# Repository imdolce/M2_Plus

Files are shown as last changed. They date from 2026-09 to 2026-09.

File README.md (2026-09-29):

# M2 Plus - 3-Phase BLDC Controller & 3A Fast-Charge Control Board







**M2 Plus** is an open-source, high-performance controller engineered as a replacement for the stock controller board came after purchase.

Built around the **WCH CH32V003F4U6** (32-bit RISC-V @ 48 MHz), the system integrates a **TI TPS61088** 10A synchronous boost converter, an **Allegro AMT49406** sensorless 3-phase BLDC controller with 6 external **AO3400** power MOSFETs, an **Injoinic IP2312** 3A fast charger with an **XB5606AJ** 1S protection circuit, and an auxiliary **WLED Breakout** daughterboard with 4x WS2812B addressable RGB LEDs and tactile button.

The project features auto-programming EEPROM configuration, 10-step throttle mapping, soft-start, smooth torque ramps, and context-aware RGB lighting animations.

> [!IMPORTANT]
> The hardware design consists of **two discrete PCBs**:
> 1. **M2 Plus Mainboard**: Handles charging, power delivery, motor control, MCU.
> 2. **WLED Breakout Board**: Houses the 4x WS2812B-2020 RGB status LEDs and the multi-function tactile user button.
> Interactive HTML Bill of Materials (iBOM) are provided for both boards in [`pcb/bom/`](pcb/bom/), and 3D CAD models in [`pcb/cad/`](pcb/cad/).

---

## PCB Image Showcase

### 3D CAD Assembly View

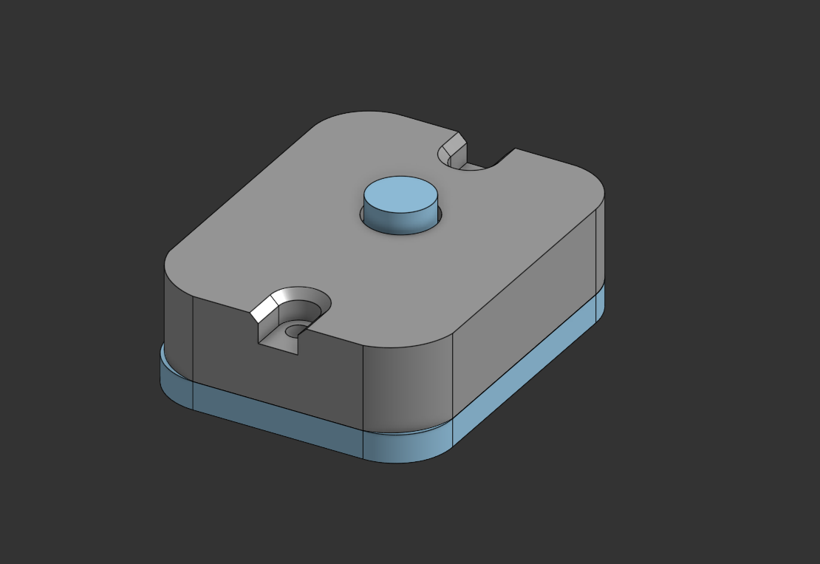
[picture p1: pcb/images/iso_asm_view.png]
M2 Plus 3D CAD Isometric Assembly View


### Fully Assembled Hardware

#### 1. M2 Plus Mainboard

| Top Side (Components & Interfaces) | Bottom Side (Power Stage & Routing) |
|:---:|:---:|
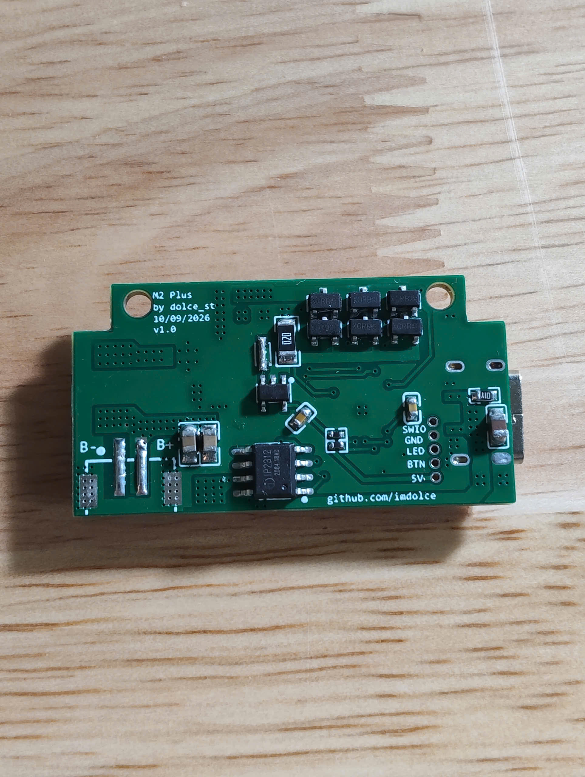
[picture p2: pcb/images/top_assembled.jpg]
M2 Plus Mainboard Top Assembled
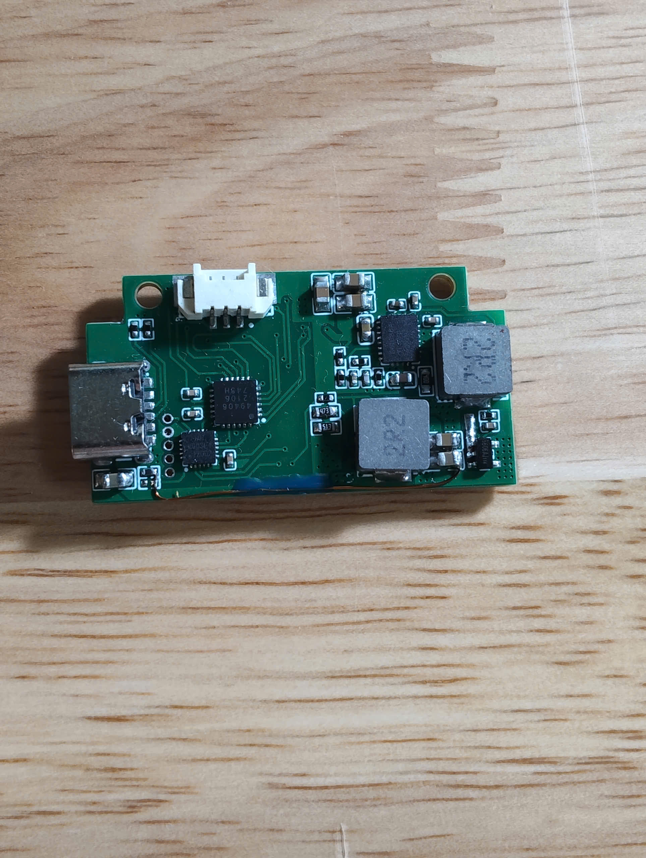
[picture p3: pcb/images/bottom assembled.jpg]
M2 Plus Mainboard Bottom Assembled
|  |  |

#### 2. WLED Breakout Board

| Front Side (Tactile Switch & Solder Pads) | Back Side (4x WS2812B LEDs) | Fully Assembled Board |
|:---:|:---:|:---:|
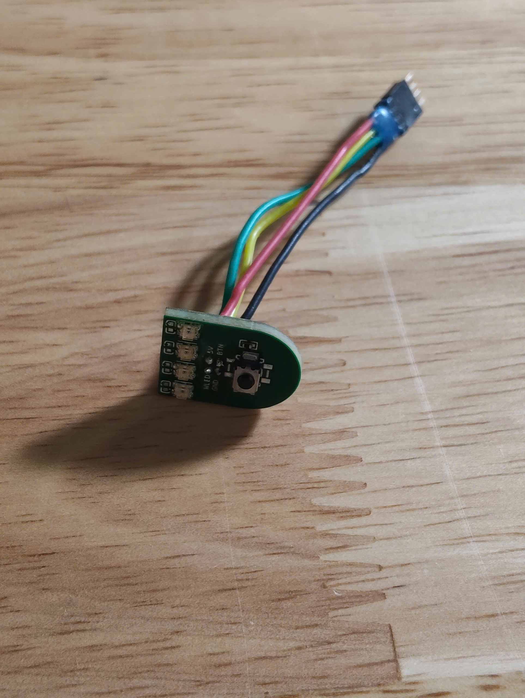
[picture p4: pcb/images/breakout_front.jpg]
WLED Breakout Front
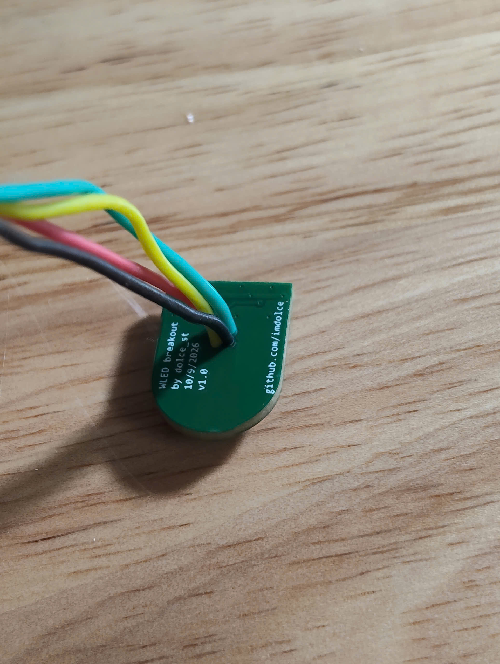
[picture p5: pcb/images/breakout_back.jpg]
WLED Breakout Back
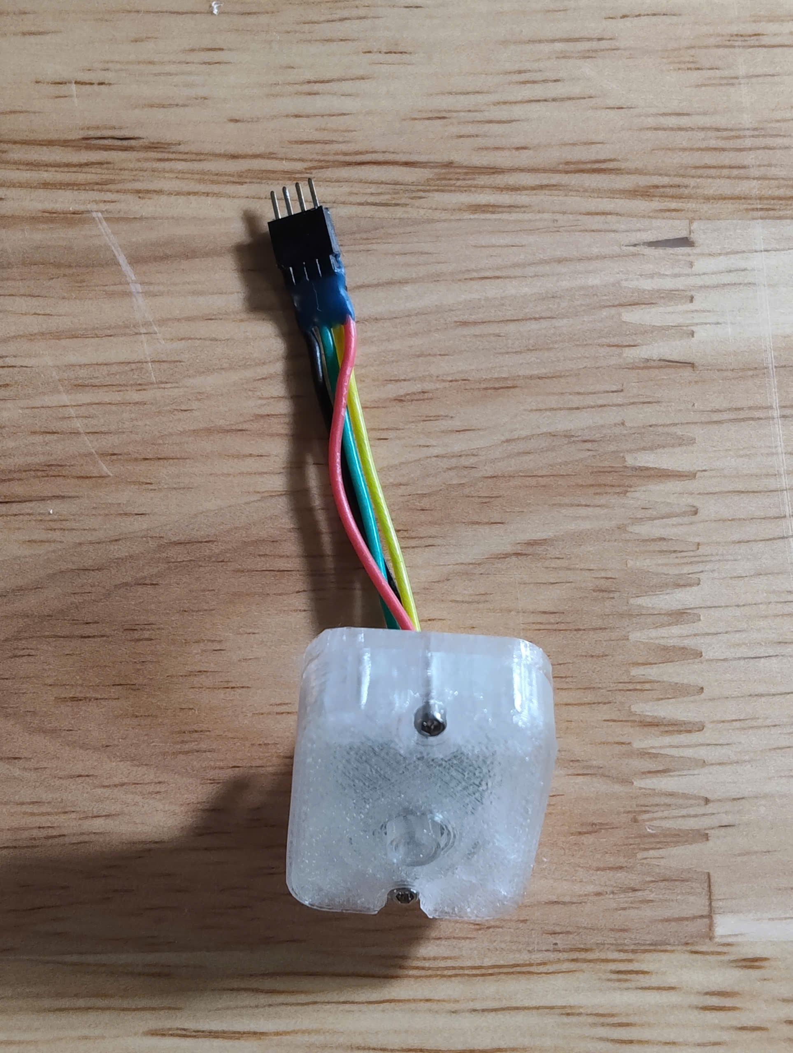
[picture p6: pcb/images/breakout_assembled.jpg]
WLED Breakout Assembled
|  |  |  |

---

## Key Features & Highlights

- **Dual-Board Modular Architecture**:
  - **M2 Plus Mainboard**: MCU, boost converter, motor bridge, and USB-C port.
  - **WLED Breakout Board**: Mini daughterboard carrying 4x WS2812B-2020 RGB status LEDs and tactile button, positioned for optimal ergonomic thumb reach and visual indication.
- **High-Power Synchronous Boost Stage**:
  - **TI TPS61088** 10A fully-integrated synchronous boost converter steps up 1S Li-ion battery voltage (3.0V – 4.2V) to 9.0V output with up to 96% efficiency.
- **Sensorless 3-Phase BLDC Driver**:
  - **Allegro AMT49406** controller paired with 6x **AO3400** N-channel MOSFETs in a discrete 3-phase inverter bridge, featuring closed-loop startup, back-EMF zero-crossing detection, programmable EEPROM motor profiles, dynamic braking, and locked-rotor protection.
- **EEPROM Auto-Verification & Self-correction**:
  - On power-up, the CH32V003 verifies the AMT49406 EEPROM registers over I2C against hardcoded golden profiles. If mismatched or unprogrammed, the MCU automatically writes and burns the EEPROM, signaling completion via Yellow LED status.
- **3.0A Fast USB-C Charging**:
  - **Injoinic IP2312** synchronous buck charging IC delivers up to 5V/3A charging current with up to 92% efficiency.
  - USB Type-C receptacle with dual 5.1kΩ CC pulldown resistors guarantees universal compatibility with USB-PD power adapters and standard C-to-C / A-to-C cables.
- **Integrated Battery Protection**:
  - On-board **XB5606AJ** single-chip battery protection IC provides hardware overcharge, over-discharge, short-circuit, and reverse polarity safety. (equivalent of DW01A + FS8205A combo, but with lower RDS(ON).)
- **10 Wind levels**:
  - 10 discrete speed steps mapped to demand values from 12% up to 100% (12, 20, 30... to 100).
  - Single tactile button press increments speed level; 11th press or a 1.5s long-press triggers a 200ms active dynamic brake pulse and turns off the fan.
- **Status LED control**:
  - WS2812B RGB runs on Timer 1 channel 1 (T1CH1).
- **Visual Feedback**:
  - **Speed Level Indication**:
    - Levels 1–4: Cyan
    - Levels 5–8: Purple
    - Levels 9–10: Lime
  - **Battery Gauge**: 4-bar readout (Red, Orange, Lime, Green) with 70 mV hysteresis and motor load sag compensation (+25 mV per speed step).
  - **Low Battery Alert**: Blinking Red warning below 3.30V; active motor cutoff below 3.05V.
  - **Charging Animation**: 0.25 Hz (4.0s period) breathing animation on the active bar while charging; solid 4 bars when fully charged.
- **Web-Based Testing Tools**:
  - **GUI Configuration Editor** ([`gui/config_editor.html`](gui/config_editor.html)): Interactive register editor for AMT49406 non-volatile EEPROM and runtime shadow registers.
  - **Firmware Simulator** ([`gui/simulator.html`](gui/simulator.html)): Pure HTML5/JavaScript simulation replicating tactile buttons, ADC inputs, WS2812B LEDs, speed state machines, and charging animations.

---

## Technical Specifications

| Parameter | Mainboard (M2 Plus) | Auxiliary Breakout (WLED Breakout) |
|:---|:---|:---|
| **MCU** | WCH CH32V003F4U6 | - |
| **Motor Controller** | Allegro AMT49406 | - |
| **Power Stage** | 6x AO3400 N-MOSFETs | - |
| **Boost Converter** | Texas Instruments TPS61088 | - |
| **Battery Charger** | Injoinic IP2312 | - |
| **Battery Protection** | XB5606AJ | - |
| **Charge Input** | USB Type-C 6-pin  | - |
| **Supported Battery** | 1S Li-ion / LiPo (3.0V – 4.2V nominal) | - |
| **Indicators / LEDs** | - | 4x WS2812B-2020 Addressable RGB LEDs |
| **User Input** | - | 1x Tactile Push Button (`TS-1088` or `SKRPACE010`) |
| **Interconnects** | USB-C, Battery 2P (`CN2`), Motor 3P (`CN1`), 5P Header (`X1`) | 4-Pin Ribbon / Solder Pads (5V, GND, DIN, BTN) |
| **PCB Layer & Size** | 2-Layer FR4, 1.6mm thickness | 2-Layer FR4, 1.6mm thickness |

---

## System Architecture & Interconnects

```
                      +-------------------------------------------------------------+
                      |                          M2 PLUS                          |
   [ USB-C 5V Input ] ---> [ IP2312 Charger ] ---> [ 1S Li-ion Battery (B+/B-) ]    |
                      |           |                         |                       |
                      |      (PA1/PA2 Sense)          [ XB5606AJ ]                  |
                      |           |                   (Protection)                  |
                      |           v                         |                       |
                      |   [ CH32V003 MCU ]             (VBAT Sense: PD6)            |
                      |     (48MHz RISC-V)                  |                       |
                      |      |           |                  v                       |
                      |      | (I2C)     |          [ TPS61088 Boost ]              |
                      |      |           |             (1S -> 9V/12V)               |
                      |      v           |                  |                       |
                      |  [ AMT49406 ]    |                  v                       |
                      |  (BLDC Driver)   |        [ 6x AO3400 MOSFETs ]             |
                      |      |           |           (3-Phase Bridge)               |
                      |      |           |                  |                       |
                      +------|-----------|------------------|-----------------------+
                             |           |                  |
                             |           |            (U / V / W Phase Lines)
                             |           |                  |
                             |           |                  v
                             |           |        [ 3-Phase BLDC Motor ]
                             |           |
               (Header / Cable Interface)|
                             |           |
                             v           v
                      +-------------------------------------+
                      |         WLED BREAKOUT BOARD         |
                      |                                     |
                      |  * 4x WS2812B-2020 Addressable LEDs |
                      |    (Data Line from MCU PD2)         |
                      |                                     |
                      |  * Tactile Push Button              |
                      |    (Active LOW Signal to MCU PD5)   |
                      +-------------------------------------+
```

---

## Schematic & Circuit Architecture

The complete circuit schematics for both boards are designed following professional EDA standards and are provided in vector PDF format alongside high-resolution preview images:

### 1. M2 Plus Mainboard Schematic
* **Vector PDF**: [`pcb/schematic/SCH_M2Plus-v1_2026-09-29.pdf`](pcb/schematic/SCH_M2Plus-v1_2026-09-29.pdf)
* **High-Resolution PNG**: [`pcb/images/SCH_M2Plus-v1_2026-09-29.png`](pcb/images/SCH_M2Plus-v1_2026-09-29.png)

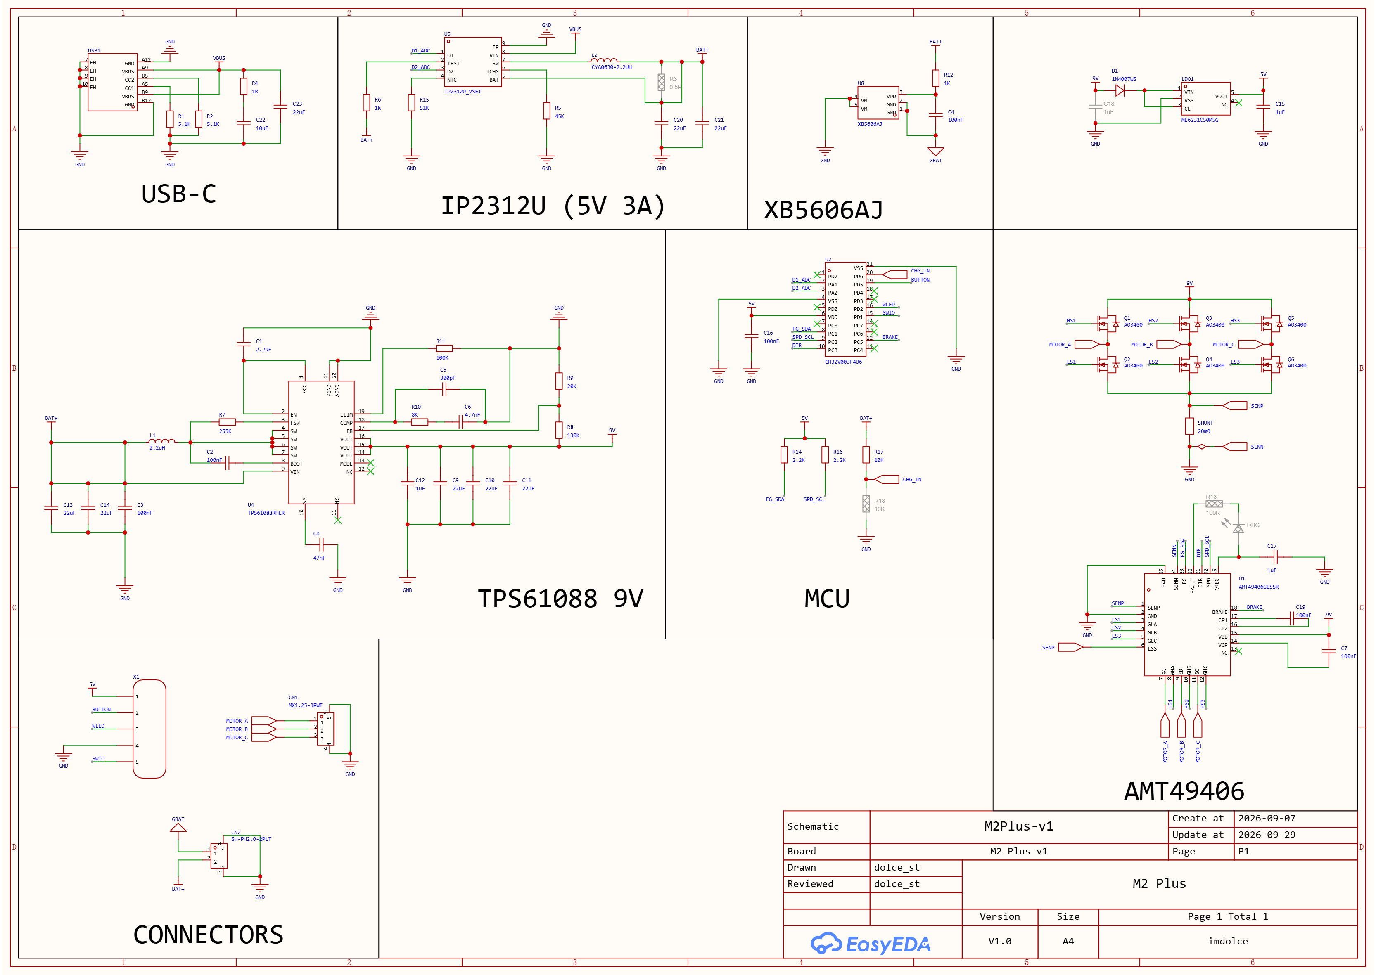
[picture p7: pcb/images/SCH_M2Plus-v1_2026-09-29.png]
M2 Plus Mainboard Schematic


---

### 2. WLED Breakout Board Schematic
* **Vector PDF**: [`pcb/schematic/SCH_WLED-Breakout_2026-09-29.pdf`](pcb/schematic/SCH_WLED-Breakout_2026-09-29.pdf)
* **High-Resolution PNG**: [`pcb/images/SCH_WLED-Breakout_2026-09-29.png`](pcb/images/SCH_WLED-Breakout_2026-09-29.png)

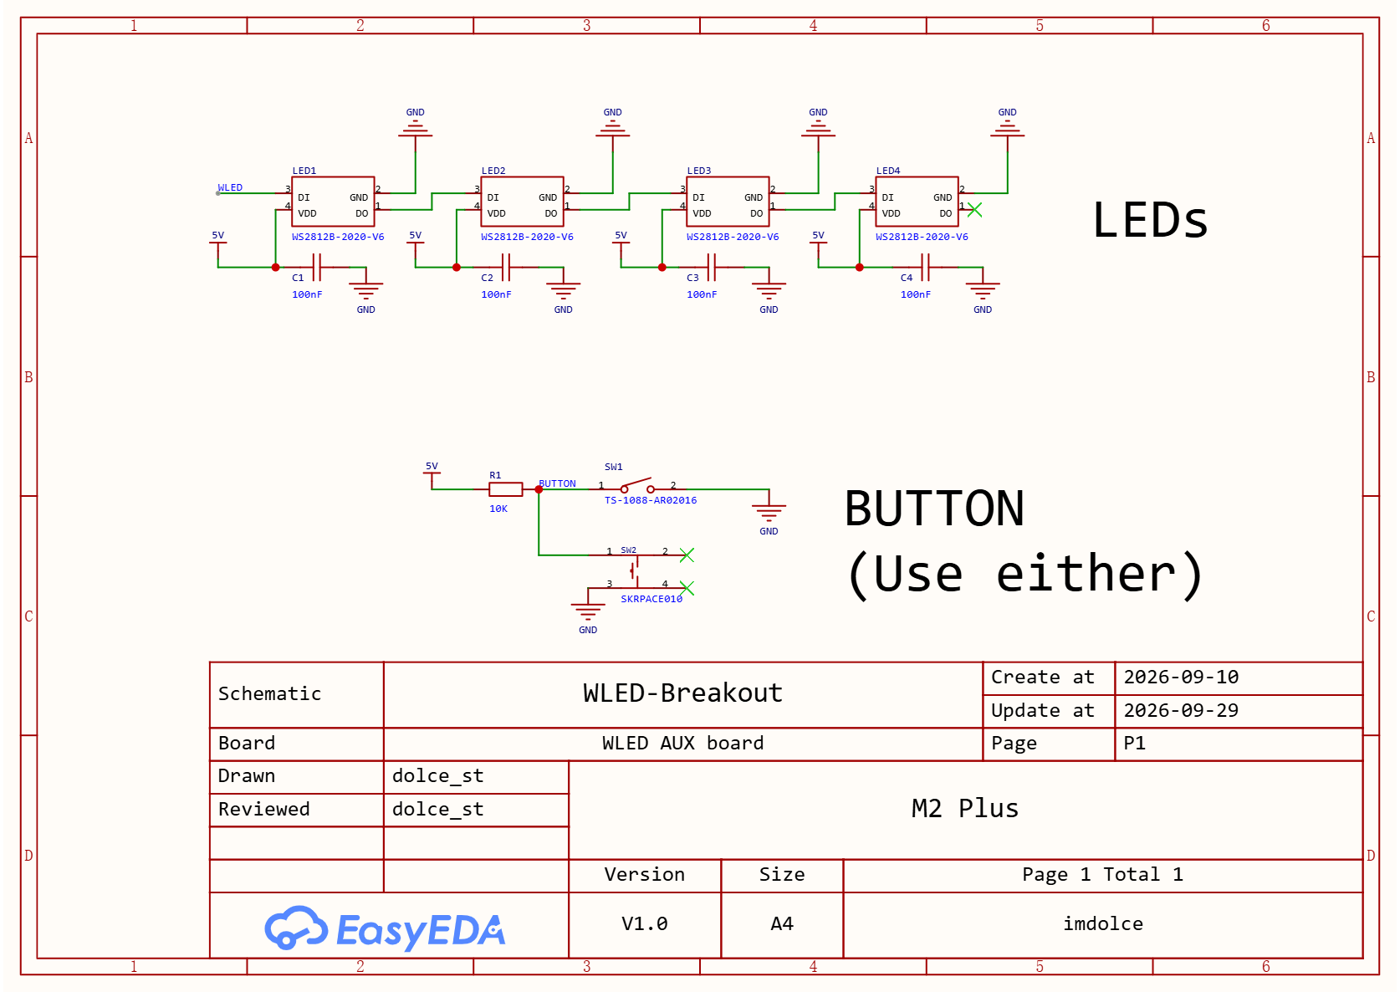
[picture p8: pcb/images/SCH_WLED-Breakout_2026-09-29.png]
WLED Breakout Board Schematic


---

## Interactive Bill of Materials & Fabrication Files

### 1. Interactive HTML BOMs
Interactive HTML Bill of Materials are generated directly from the layout files for simplified hand assembly, inspection, and part ordering:

* **M2 Plus Mainboard iBOM**: [`pcb/bom/M2Plus-interactive-bom.html`](pcb/bom/M2Plus-interactive-bom.html) (57 components, 35 unique lines)
* **WLED Breakout Board iBOM**: [`pcb/bom/WLED-breakout-interactive-bom.html`](pcb/bom/WLED-breakout-interactive-bom.html) (11 components, 5 unique lines)

### 2. Gerber Fabrication Packages
Ready-to-order Gerber packages (2-layer FR4, 1.6mm thickness) for PCB prototyping or production:

* **M2 Plus Mainboard Gerbers**: [`pcb/gerber/M2-plus-v1_2026-09-29.zip`](pcb/gerber/M2-plus-v1_2026-09-29.zip)
* **WLED Breakout Board Gerbers**: [`pcb/gerber/WLED-breakout_2026-09-29.zip`](pcb/gerber/WLED-breakout_2026-09-29.zip)

### 3. PCB 3D STEP Models
Complete 3D ECAD models for mechanical integration and CAD modeling:

* **M2 Plus Mainboard 3D STEP**: [`pcb/cad/3D_m2plus_2026-09-29.step`](pcb/cad/3D_m2plus_2026-09-29.step)
* **WLED Breakout Board 3D STEP**: [`pcb/cad/3D_breakout_2026-09-29.step`](pcb/cad/3D_breakout_2026-09-29.step)

### 4. Summary Component Table

> [!NOTE]
> **Notice on 1.27mm Headers**:
> Standard 1.27mm pitch male pin headers (for mainboard programming port `X1`) and mating 1.27mm female headers / ribbon connectors are **not explicitly mentioned inside the generated BOM files** (`.html`). Please ensure you source 1.27mm male pin headers and 1.27mm 4-pin female receptacles to connect to the auxillary board.

#### M2 Plus Mainboard (PCB1)

| Designator | Value / Part | Package / Footprint | Description / LCSC Part # |
|:---|:---|:---|:---|
| **U1** | AMT49406GESSR | TQFN-24 (4x4mm, 0.5mm pitch) | Allegro 3-Phase Sensorless BLDC Driver (`C2066114`) |
| **U2** | CH32V003F4U6 | QFN-20 (3x3mm, 0.4mm pitch) | WCH 32-bit RISC-V MCU @ 48 MHz (`C5299908`) |
| **U4** | TPS61088RHLR | VQFN-20 (4.5x3.5mm, 0.5mm pitch) | TI 10A Synchronous Boost Converter (`C87357`) |
| **U5** | IP2312U_VSET | SOP-8-EP (4.9x3.9mm, 1.27mm pitch) | Injoinic 3A Synchronous Buck Charger (`C605432`) |
| **U8** | XB5606AJ | SOT-23-5 | Monolithic 1S Li-ion Protection IC (`C669680`) |
| **LDO1** | ME6231C50M5G | SOT-23-5 | High-PSRR 5.0V LDO Voltage Regulator (`C2765183`) |
| **Q1 – Q6** | AO3400 | SOT-23 | 30V 5.7A N-Channel Power MOSFETs (`C20628874`) |
| **L1** | APS0630 2.2uH | SMD Inductor 7.7x6.6mm | High-Current Boost Inductor (`C47327201`) |
| **L2** | CYA0630 2.2uH | SMD Inductor 7.2x6.6mm | Charger Buck Inductor (`C5189746`) |
| **SHUNT** | 20mΩ | SMD 1206 | Current Sense Resistor (`C7420010`) |
| **D1** | 1N4007WS | SOD-323 | General Purpose Switching Diode (`C53055759`) |
| **USB1** | TYPE-C 6P | SMD Type-C 6P | USB Type-C Receptacle with CC resistors |
| **CN1** | MX1.25-3PWT | SMD 3-Pin MX1.25 | BLDC Motor Phase Connector (`C52037387`) |
| **CN2** | SH-PH2.0-2PLT | SMD 2-Pin PH2.0 | 1S Battery Connector (`C53477406`) |
| **X1** | 1.27mm 1x5P Male Header | 1.27mm Pitch (5x1) | Single-Wire Programming & Debug Interface *(Not explicitly in BOM)* |
| **-** | 1.27mm 1x5P Female Header | 1.27mm Pitch (5x1) | Mating connector for WCH-Link SWD cable *(Not explicitly in BOM)* |
| **C9 – C11, C13, C14, C20, C21, C23** | 22µF | 0805 | High-Capacitance Filter Capacitors (`C602037`) |
| **C22** | 10µF | 0805 | Bypass Capacitor |
| **C1, C12, C15, C17** | 1µF / 2.2µF | 0603 | Decoupling Capacitors |
| **C2 – C4, C7, C16, C19** | 100nF | 0402 | High-Frequency Decoupling Capacitors (`C1525`) |
| **C5, C6, C8** | 300pF, 4.7nF, 47nF | 0402 | AMT49406 Filter & Compensation Capacitors |
| **R1, R2** | 5.1kΩ ±1% | 0402 | USB Type-C CC1 / CC2 Pull-Down Resistors |
| **R14, R16** | 2.2kΩ ±1% | 0402 | I2C Bus Pull-Up Resistors (SDA / SCL) |
| **R17** | 10kΩ ±1% | 0402 | Pull-Up / Sensing Bias Resistor |
| **R6, R12** | 1kΩ ±1% | 0402 | Current Limiting Resistors |
| **R8, R9, R10, R11** | 130kΩ, 20kΩ, 8kΩ, 100kΩ | 0402 | TPS61088 Feedback & Compensation Resistors |
| **R4, R5, R7, R15** | 1Ω, 45kΩ, 255kΩ, 51kΩ | 0603 | Power & Bias Resistors |

#### WLED Breakout Board (PCB2)

| Designator | Value / Part | Package / Footprint | Description / LCSC Part # |
|:---|:---|:---|:---|
| **LED1 – LED4** | WS2812B-2020-V6 | SMD 4P (2.0x2.0mm) | Ultra-compact Addressable RGB LEDs (`C52917434`) |
| **C1 – C4** | 100nF | 0402 | Local RGB LED Decoupling Capacitors (`C1525`) |
| **R1** | 10kΩ ±1% | 0402 | Button Hardware Pull-Up Resistor |
| **SW1 / SW2** | TS-1088 or SKRPACE010 | SMD 2-Pin / 4-Pin Tactile Switch | Multi-function User Control Button (`C720477` / `C139797`) |

---

## 3D CAD & Enclosure Mechanical Files

All 3D CAD models, PCB STEP files, and 3D-printable enclosure models are located in [`pcb/cad/`](pcb/cad/):

### 1. PCB 3D CAD Models (ECAD / MCAD)

| File | Format | Size | Description |
|:---|:---:|:---:|:---|
| **[`3D_m2plus_2026-09-29.step`](pcb/cad/3D_m2plus_2026-09-29.step)** | STEP | ~26 MB | 3D ECAD model of the M2 Plus Mainboard PCB with all mounted components |
| **[`3D_breakout_2026-09-29.step`](pcb/cad/3D_breakout_2026-09-29.step)** | STEP | ~4.6 MB | 3D ECAD model of the WLED Breakout Board PCB with all mounted components |

### 2. Enclosure Shells & Master Assembly

| File | Format | Description |
|:---|:---:|:---|
| **[`full_assembly.step`](pcb/cad/full_assembly.step)** | STEP | Master 3D CAD assembly (PCBs, enclosure shells, button, fasteners) |
| **[`bottom_shell.stl`](pcb/cad/bottom_shell.stl)** | STL | Bottom enclosure body housing the M2 Plus Mainboard, battery bay, and USB-C port |
| **[`upper_shell.stl`](pcb/cad/upper_shell.stl)** | STL | Upper enclosure body housing the WLED breakout board and motor airflow channel |
| **[`button.stl`](pcb/cad/button.stl)** | STL | 3D-printable multi-function tactile button actuator |

### Required Fasteners
* **Enclosure Screws**: **M1.4 × 6 mm SHCS** (Socket Head Cap Screws)

---

## Installation & Assembly Instructions

*Coming soon.*

---

## Speed Table

The firmware maps 10 discrete user levels to the AMT49406 9-bit demand register (`0` to `511`). Demands below 12% (65) are treated by the motor driver as zero-throttle stop:

| Speed Level | Demand (Raw) | Throttle (%) | LED Status Indicator (1.5s Display) |
|:---:|:---:|:---:|:---:|
| **Level 0 (Off)** | `0` | 0% | All LEDs OFF |
| **Level 1** | `65` | 12% | 1 LED Cyan |
| **Level 2** | `107` | 21% | 2 LEDs Cyan | 
| **Level 3** | `158` | 31% | 3 LEDs Cyan |
| **Level 4** | `210` | 41% | 4 LEDs Cyan |
| **Level 5** | `261` | 51% | 1 LED Purple | 
| **Level 6** | `312` | 61% | 2 LEDs Purple | 
| **Level 7** | `363` | 71% | 3 LEDs Purple |
| **Level 8** | `414` | 81% | 4 LEDs Purple |
| **Level 9** | `465` | 91% | 2 LEDs Lime |
| **Level 10** | `511` | 100% | 4 LEDs Lime |

---

## User Control & LED Status Indicators

```
  Short Press (Click)          Long Press (1.5s)
 [ L1 -> L2 -> ... -> L10 ]   [ Immediate Emergency Stop ]
          |                              |
 (11th Click: Motor Off)          (Dynamic Brake: 200ms)
```

### 1. Speed Feedback Mode (First 1.5 seconds after button press)
* **Levels 1 – 4**: 1 to 4 LEDs illuminate in **Cyan**.
* **Levels 5 – 8**: 1 to 4 LEDs illuminate in **Purple**.
* **Levels 9 – 10**: 2 or 4 LEDs illuminate in **Lime**.

### 2. Battery Status Gauge (After 1.5s timeout while running)
* **4 Bars (≥ 3.90V)**: Red + Orange + Lime + Green (Solid).
* **3 Bars (≥ 3.70V)**: Red + Orange + Lime.
* **2 Bars (≥ 3.50V)**: Red + Orange.
* **1 Bar (≥ 3.35V)**: Red.
* **Low Battery (< 3.30V)**: Lowest LED blinks in **Red** (2 Hz).
* **Cutoff Voltage (< 3.05V)**: All LEDs flash **Red** 3 times $\rightarrow$ Motor stops $\rightarrow$ Board enters `STATE_OFF`.

### 3. Charging Mode (USB Plugged In)
* **Active Charging**: Highest active battery bar breathes with a smooth  **0.25 Hz** breathing effect.
* **Full Charge**: All 4 LEDs illuminate **Solid Green/Lime** with no breathing.
* **Off State (Unplugged)**: All LEDs remain completely dark to preserve battery standby power.

---

## Building and Flashing

### Requirements
* [PlatformIO](https://platformio.org/) (CLI or VS Code Extension).
* WCH-LinkE or compatible WCH-Link RISC-V programmer.

### 1. Build Firmware
```bash
pio run
```
Or click the checkmark button.
### 2. Connect Hardware Programmer
Connect your WCH-Link programmer to the 5-pin programming header (`X1`) on the M2 Plus board:
* **`5V`** $\rightarrow$ `VCC`
* **`GND`** $\rightarrow$ `GND`
* **`PD1`** $\rightarrow$ `SWIO`

### 3. Flash to Target
```bash
pio run --target upload
```
Or click the right arrow button.

---

## Web-Based Testing tools

### 1. GUI Configuration Editor (`gui/config_editor.html`)
An interactive register map editor for the Allegro AMT49406 motor controller:
* Load, edit, and save JSON configuration profiles (`amt49406_config0.json`, `amt49406_config1.json`).
* Visual decoding of EEPROM registers 0 through 11 (Pole pairs, current sense gain, open-loop acceleration, lead angle, current limits).
* Export C header arrays for direct compilation into `config_manager.c`.

### 2. Firmware Simulator (`gui/simulator.html`)
A complete browser-based hardware and firmware simulation tool:
* Interactive virtual tactile push button with debouncing and long-press detection.
* Dynamic 4x WS2812B RGB visual rendering showing speed levels, battery gauge, and 0.25 Hz charging breathing.
* Interactive USB-C cable plug/unplug simulation, voltage adjustment, and motor load emulation.

---

## License & Credits

- **Hardware Design**: Designed by **[dolce_st](https://github.com/imdolce)**.
- **GUI, tools and firmware development**: Designed by Google Gemini.
- **Documentation**: Written by Google Gemini, proofread & corrected by dolce_st.
- **License**: Released under the [CERN Open Hardware Licence Version 2 - Strongly Reciprocal / Permissive](https://ohwr.org/cern_ohl) for hardware, and the [MIT License](LICENSE) for firmware.

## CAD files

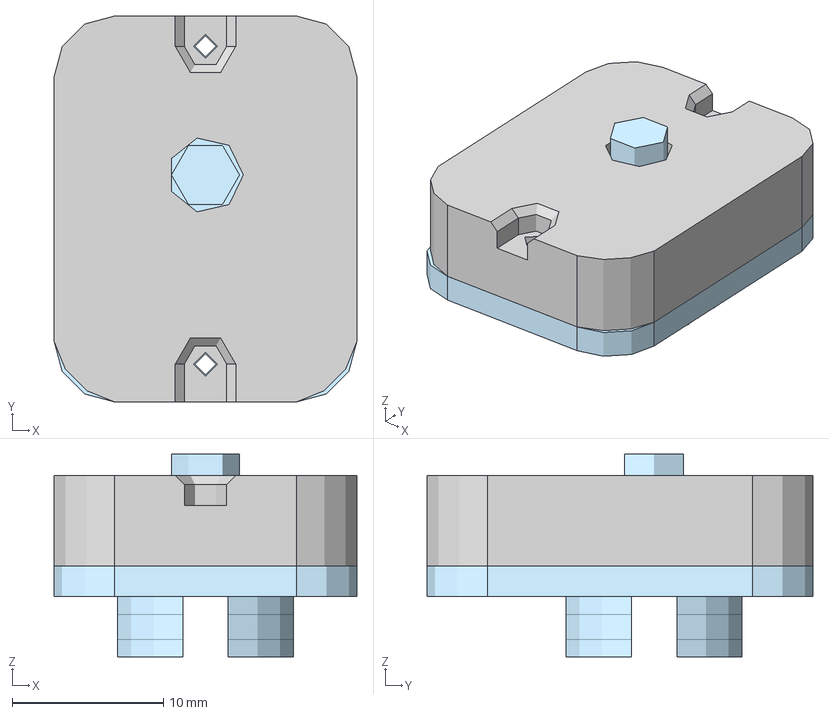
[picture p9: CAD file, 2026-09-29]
pcb/cad/full_assembly.step
20.0 x 25.5 x 13.4 mm
SW-SMD_L3.9-W3.0-P4.45~SW-SMD_L3.9-W2.9-H2.0-LS4.8~8KUx__Í¹Ì ¨-ï¿½ï¿½ï¿½ï¿½6[1]
C0402~C0402_L1.0-W0.5-H0.5~vaH2__Í¹Ì¨-ï¿½ ï¿½ï¿½ï¿½3_3
SW-SMD_L3.9-W3.0-P4.45~SW-SMD_L3.9-W2.9-H2.0-LS4.8~8KUx__Í¹Ì ¨-ï¿½ï¿½ï¿½ï¿½7[2]
SW-SMD_L3.9-W3.0-P4.45~SW-SMD_L3.9-W2.9-H2.0-LS4.8~8KUx__ï¿½ Ð³ï¿½-ï¿½ï¿½ï¿½ ï¿½6
C0402~C0402_L1.0-W0.5-H0.5~vaH2__Í¹Ì¨-ï¿½ ï¿½ï¿½ï¿½3_2
SW-SMD_L3.9-W3.0-P4.45~SW-SMD_L3.9-W2.9-H2.0-LS4.8~8KUx__Í¹Ì ¨-ï¿½ï¿½ï¿½ï¿½7[3]
SW-SMD_L3.9-W3.0-P4.45~SW-SMD_L3.9-W2.9-H2.0-LS4.8~8KUx__Í¹Ì ¨-ï¿½ï¿½ï¿½ï¿½6[2]
C0402~C0402_L1.0-W0.5-H0.5~vaH2__Í¹Ì¨-ï¿½ ï¿½ï¿½ï¿½3_1
SW-SMD_L3.9-W3.0-P4.45~SW-SMD_L3.9-W2.9-H2.0-LS4.8~8KUx__Í¹Ì ¨-ï¿½ï¿½ï¿½ï¿½7[4]
SW-SMD_L3.9-W3.0-P4.45~SW-SMD_L3.9-W2.9-H2.0-LS4.8~8KUx__Í¹Ì ¨-ï¿½ï¿½ï¿½ï¿½7[1]
C0402~C0402_L1.0-W0.5-H0.5~vaH2__Í¹Ì¨-ï¿½ ï¿½ï¿½ï¿½3
SW-SMD_L3.9-W3.0-P4.45~SW-SMD_L3.9-W2.9-H2.0-LS4.8~8KUx__Í¹Ì ¨-ï¿½ï¿½ï¿½ï¿½7[5]
R0402~R0402_L1.0-W0.5-H0.4~NAg5__Í¹Ì¨-ï¿½ ï¿½ï¿½ï¿½5
SW-SMD_L3.9-W3.0-P4.45~SW-SMD_L3.9-W2.9-H2.0-LS4.8~8KUx__Í¹Ì ¨-ï¿½ï¿½ï¿½ï¿½7[6]
R0402~R0402_L1.0-W0.5-H0.4~NAg5__ï¿½ï¿½ï¿ ½ï¿½1 x 2
SW-SMD_L3.9-W3.0-P4.45~SW-SMD_L3.9-W2.9-H2.0-LS4.8~8KUx__Í¹Ì ¨-ï¿½ï¿½ï¿½ï¿½7[7]
LED-SMD_4P-L2.2-W2.0-P1.00_WS2815C-2020-4P~default_model~J6fo_3
SW-SMD_L3.9-W3.0-P4.45~SW-SMD_L3.9-W2.9-H2.0-LS4.8~8KUx__Í¹Ì ¨-ï¿½ï¿½ï¿½ï¿½7[8]
LED-SMD_4P-L2.2-W2.0-P1.00_WS2815C-2020-4P~default_model~J6fo_2
SW-SMD_L3.9-W3.0-P4.45~SW-SMD_L3.9-W2.9-H2.0-LS4.8~8KUx__Í¹Ì ¨-ï¿½ï¿½ï¿½ï¿½7[9]
LED-SMD_4P-L2.2-W2.0-P1.00_WS2815C-2020-4P~default_model~J6fo_1
SW-SMD_L3.9-W3.0-P4.45~SW-SMD_L3.9-W2.9-H2.0-LS4.8~8KUx__Í¹Ì ¨-ï¿½ï¿½ï¿½ï¿½7[10 ]
LED-SMD_4P-L2.2-W2.0-P1.00_WS2815C-2020-4P~default_model~J6fo
SW-SMD_L3.9-W3.0-P4.45~SW-SMD_L3.9-W2.9-H2.0-LS4.8~8KUx__Í¹Ì ¨-ï¿½ï¿½ï¿½ï¿½7[11 ]
Board~J6fo
SW-SMD_L3.9-W3.0-P4.45~SW-SMD_L3.9-W2.9-H2.0-LS4.8~8KUx__Í¹Ì ¨-ï¿½ï¿½ï¿½ï¿½7[12 ]
SW-SMD_L3.9-W3.0-P4.45~SW-SMD_L3.9-W2.9-H2.0-LS4.8~8KUx__Í¹Ì ¨-ï¿½ï¿½ï¿½ï¿½7[13 ]

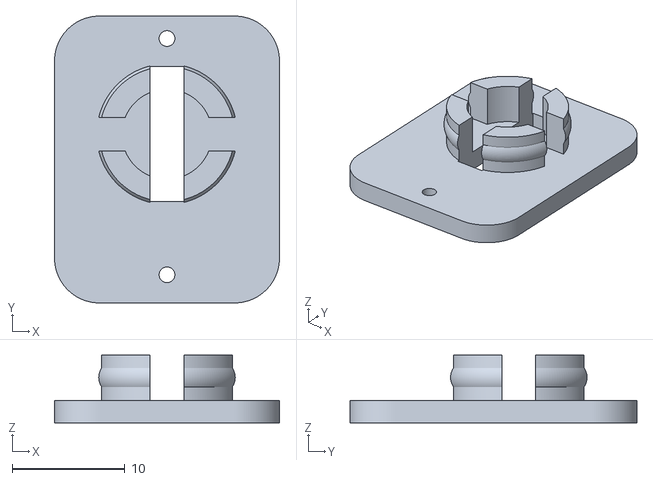
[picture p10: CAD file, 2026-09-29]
pcb/cad/bottom_shell.stl
20.0 x 25.5 x 6.00

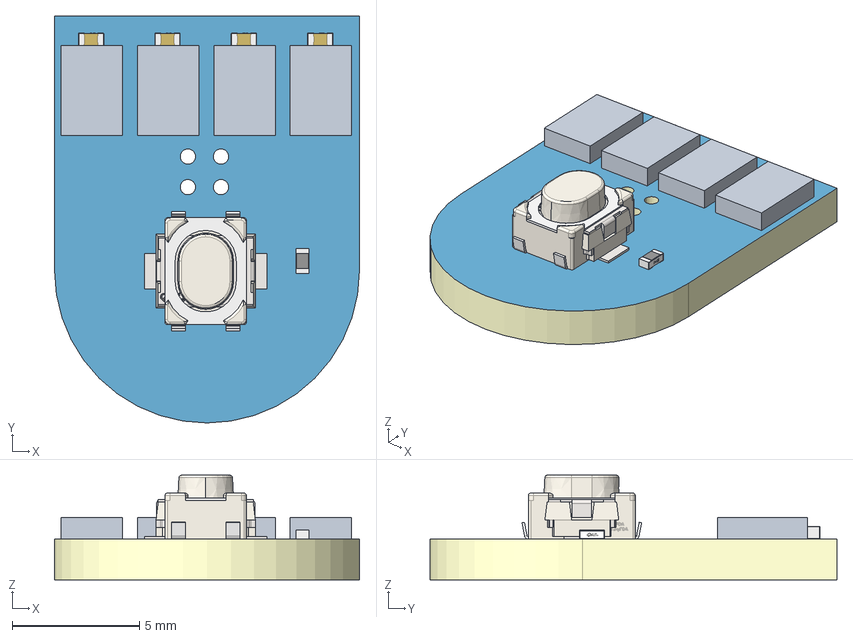
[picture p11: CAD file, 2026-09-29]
pcb/cad/3D_breakout_2026-09-29.step
12.0 x 16.0 x 4.11 mm
Board~ZU9K
TopCopper~ZU9K
BottomCopper~ZU9K
TopSilkscreen~ZU9K
BottomSilkscreen~ZU9K
TopFpcStiffener~ZU9K
BottomFpcStiffener~ZU9K
LED-SMD_4P-L2.2-W2.0-P1.00_WS2815C-2020-4P~default_model~ZU9K x 4
R0402~R0402_L1.0-W0.5-H0.4~Ijj9
SW-SMD_L3.9-W3.0-P4.45~SW-SMD_L3.9-W2.9-H2.0-LS4.8~zRqP
C0402~C0402_L1.0-W0.5-H0.5~45uo x 4
KEY-SMD_4P-L4.2-W3.2-P2.20-LS4.6~KEY-SMD_4P-L4.2-W3.2-H2.5-LS4.6-P2.2~OajB

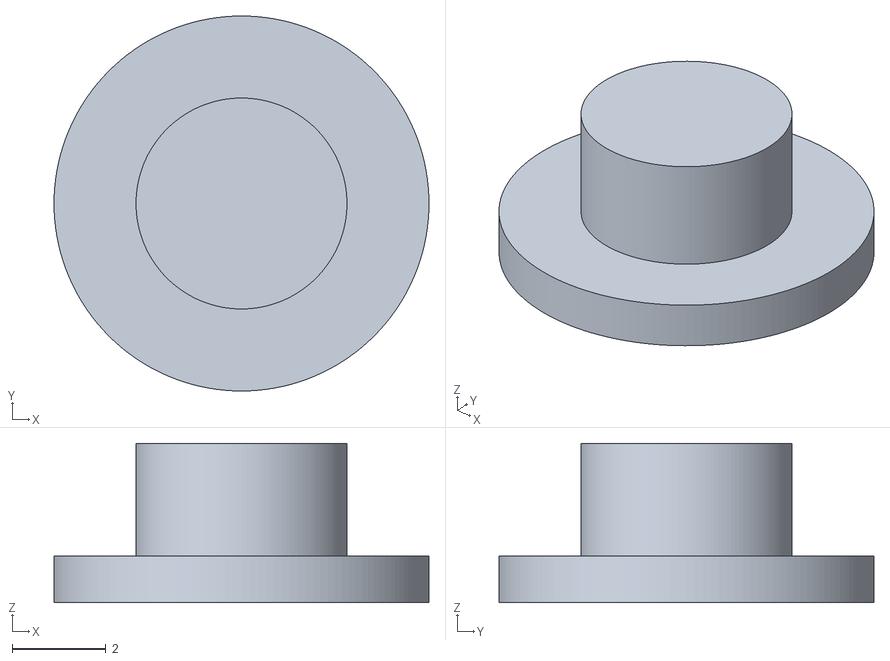
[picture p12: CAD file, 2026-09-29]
pcb/cad/button.stl
8.00 x 8.00 x 3.40

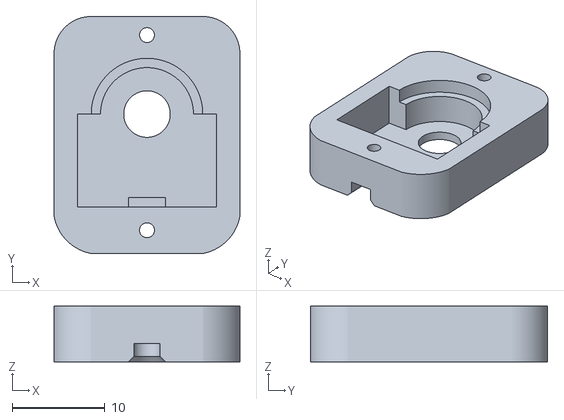
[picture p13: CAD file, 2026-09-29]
pcb/cad/upper_shell.stl
20.0 x 25.5 x 6.00

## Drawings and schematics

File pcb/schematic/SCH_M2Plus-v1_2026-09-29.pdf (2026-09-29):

C18
1uF

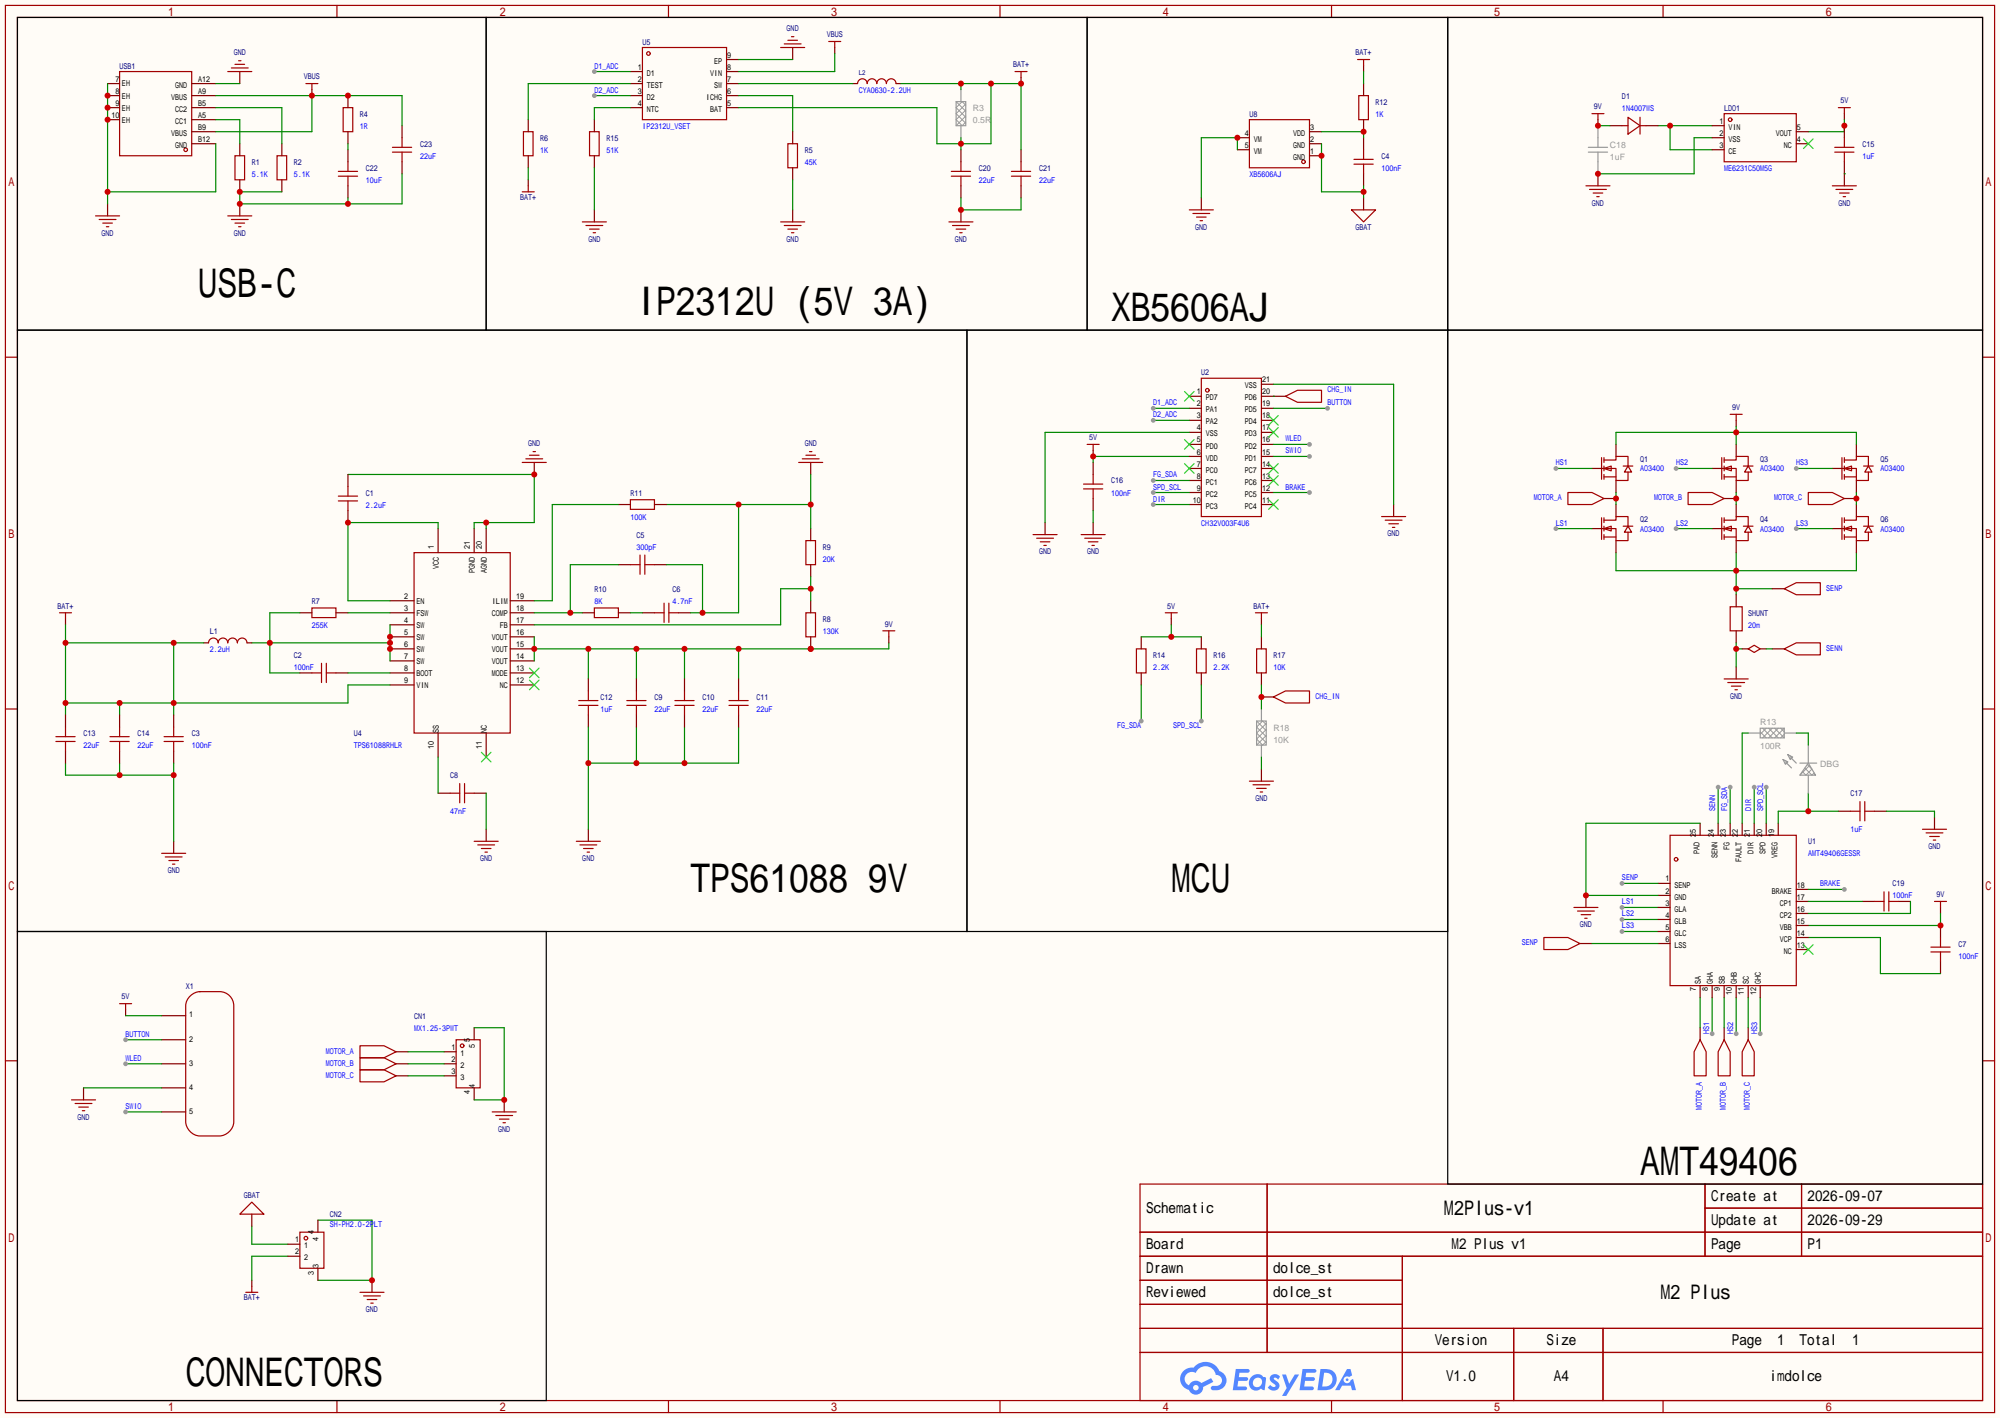
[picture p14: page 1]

Schematic | M2Plus-v1 | Create at | 2026-09-07

Update at | 2026-09-29

Board | M2 Plus v1 | Page | P1
Drawn | dolce_st | M2 Plus
Reviewed | dolce_st

Version | Size | Page 1 Total 1

V1.0 | A4 | imdolce

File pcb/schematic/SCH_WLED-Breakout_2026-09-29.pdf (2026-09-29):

# LEDs

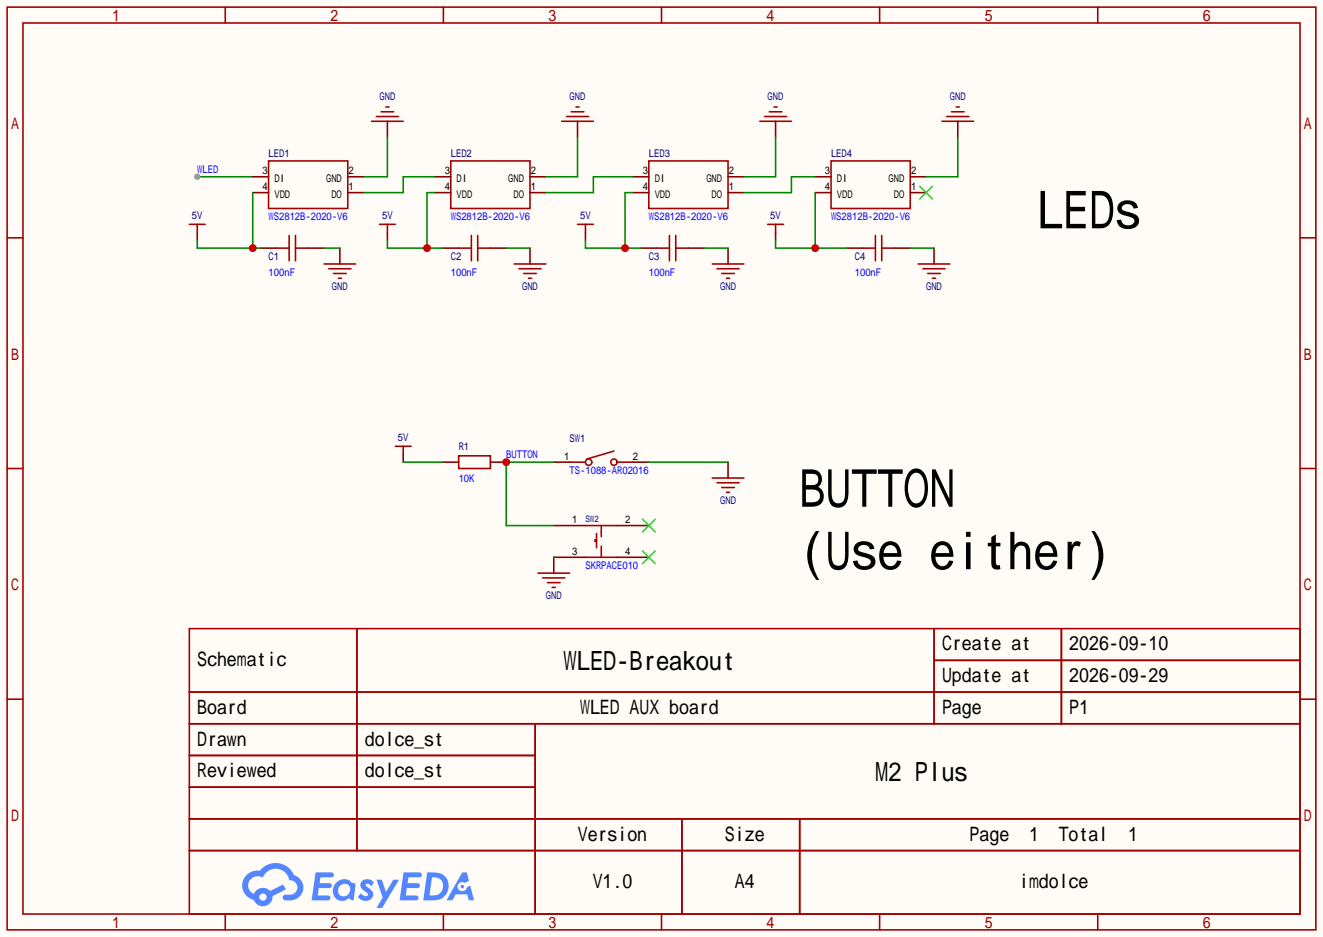
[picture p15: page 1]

Schematic | WLED-Breakout | Create at | 2026-09-10

Update at | 2026-09-29

Board | WLED AUX board | Page | P1
Drawn | dolce_st | M2 Plus
Reviewed | dolce_st

Version | Size | Page 1 Total 1

V1.0 | A4 | imdolce

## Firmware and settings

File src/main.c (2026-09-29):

#include "amt49406.h"
#include "battery.h"
#include "button.h"
#include "config_manager.h"
#include "ws2812.h"
#include <ch32v00X.h>
#include <debug.h>

/* Operating States */
typedef enum { STATE_OFF = 0, STATE_RUNNING } app_state_t;

/* 10 Speed Throttle Mapping Table (Demand 0 to 511)
 * Discrete levels from 12% (65) to 100% (511).
 * (Demand <= 10% / 51 is interpreted as 0% stop by AMT49406). */
static const uint16_t SPEED_THROTTLE_TABLE[11] = {
    0,   /* Level 0: Off */
    65,  /* Level 1: 12% */
    107, /* Level 2: 21% */
    158, /* Level 3: 31% */
    210, /* Level 4: 41% */
    261, /* Level 5: 51% */
    312, /* Level 6: 61% */
    363, /* Level 7: 71% */
    414, /* Level 8: 81% */
    465, /* Level 9: 91% */
    511  /* Level 10: 100% */
};

#define SPEED_FEEDBACK_DELAY_MS                                                \
  1500 /* 1.5s delay before reverting to battery status */

/* Interrupt Handlers */
void NMI_Handler(void) __attribute__((interrupt("WCH-Interrupt-fast")));
void HardFault_Handler(void) __attribute__((interrupt("WCH-Interrupt-fast")));
void EXTI7_0_IRQHandler(void) __attribute__((interrupt("WCH-Interrupt-fast")));

void NMI_Handler(void) {}
void HardFault_Handler(void) {
  /* If a hard fault occurs, set LEDs to solid red and halt */
  ws2812_set_all(COLOR_RED);
  ws2812_update();
  while (1)
    ;
}

void EXTI7_0_IRQHandler(void) {
  if (EXTI_GetITStatus(EXTI_Line5) != RESET) {
    EXTI_ClearITPendingBit(EXTI_Line5);
  }
  if (EXTI_GetITStatus(EXTI_Line1) != RESET) {
    EXTI_ClearITPendingBit(EXTI_Line1);
  }
}

int main(void) {
  NVIC_PriorityGroupConfig(NVIC_PriorityGroup_1);
  SystemCoreClockUpdate();
  Delay_Init();

  /* 1. Initialize Peripherals */
  ws2812_init();
  button_init();
  Battery_Init();
  AMT49406_GPIO_Init();
  AMT49406_I2C_Init();

  /* 2. AMT49406 Power Window Capture & I2C Handshake */
  uint16_t elapsed = 0;
  AMT49406_Capture_Boot_Window(800, &elapsed);

  /* 3. EEPROM Auto-Verification & Self-Healing */
  config_status_t cfg_status = Config_VerifyEEPROM();

  if (cfg_status == CONFIG_STATUS_MISMATCH) {
    /* Config mismatch or fresh unprogrammed chip: Auto-flash golden
     * configuration */
    cfg_status = Config_FlashEEPROM();

    if (cfg_status == CONFIG_STATUS_MATCH) {
      /* Flashing successful: Set LEDs to Yellow.
       * User/programmer must power cycle the system once to apply non-volatile
       * registers. */
      ws2812_set_all(COLOR_YELLOW);
      ws2812_update();
      while (1) {
        Delay_Ms(500);
      }
    } else {
      /* Flash verification failed: Set LEDs to Red and halt */
      ws2812_set_all(COLOR_RED);
      ws2812_update();
      while (1) {
        Delay_Ms(500);
      }
    }
  } else if (cfg_status == CONFIG_STATUS_ERROR) {
    /* I2C communication error: Try bus recovery and retry once */
    AMT49406_I2C_Bus_Recover();
    cfg_status = Config_VerifyEEPROM();
    if (cfg_status != CONFIG_STATUS_MATCH) {
      ws2812_set_all(COLOR_RED);
      ws2812_update();
      while (1) {
        Delay_Ms(500);
      }
    }
  }

  /* Verification Passed: Set all LEDs to Green for 1.2s to confirm check OK */
  ws2812_set_all(COLOR_GREEN);
  ws2812_update();
  Delay_Ms(1200);

  /* 4. Start in OFF state waiting for user button press or charger */
  app_state_t state = STATE_OFF;
  uint8_t current_level = 0;
  uint16_t charging_phase_ms = 0;
  uint8_t blink_counter = 0;
  uint16_t speed_feedback_timer_ms = 0;
  uint16_t off_adc_timer_ms = 0;
  uint16_t running_adc_timer_ms = 0;
  uint8_t prev_charging = 0;

  AMT49406_SetSpeed(0);
  AMT49406_SetBrake(0);
  Battery_ResetChargeDetect();
  ws2812_clear();
  ws2812_update();

  while (1) {
    /* --------------------------------------------------------
     * STATE: OFF (Fan speed 0)
     * -------------------------------------------------------- */
    if (state == STATE_OFF) {
      /* 1. Poll button every 20ms */
      button_poll(20);
      if (button_get_event() == BUTTON_EVENT_SHORT_PRESS) {
        state = STATE_RUNNING;
        current_level = 1; /* Start at Level 1 (11%) */
        speed_feedback_timer_ms = SPEED_FEEDBACK_DELAY_MS;
        AMT49406_SetSpeed(SPEED_THROTTLE_TABLE[current_level]);
        running_adc_timer_ms = 0;
        continue;
      }

      /* 2. Poll ADC every 500ms */
      off_adc_timer_ms += 20;
      if (off_adc_timer_ms >= 500) {
        off_adc_timer_ms = 0;
        Battery_Update(0);
      }

      /* 3. LED Behavior in OFF state:
       * If charging: indicate charge status (0.25 Hz breathing, or solid if
       * full) If not charging: all LEDs stay completely OFF */
      if (Battery_IsCharging()) {
        charging_phase_ms = (charging_phase_ms + 20) %
                            4000; /* 0.25 Hz breathing (4000ms period) */
        ws2812_show_charging(Battery_GetBars(), charging_phase_ms,
                             Battery_IsFullCharge());
        prev_charging = 1;
      } else {
        if (prev_charging) {
          ws2812_clear();
          ws2812_update();
          prev_charging = 0;
          charging_phase_ms = 0;
        }
      }

      Delay_Ms(20);
      continue;
    }

    /* --------------------------------------------------------
     * STATE: RUNNING (Fan speed Level 1 to 10)
     * -------------------------------------------------------- */
    if (state == STATE_RUNNING) {
      button_poll(20);
      button_event_t btn_ev = button_get_event();

      /* Short Press: Cycle to next wind level (1 to 10), or turn off if beyond
       * max (10) */
      if (btn_ev == BUTTON_EVENT_SHORT_PRESS) {
        current_level++;
        if (current_level > 10) {
          /* Click at max throttle (level 10) -> Turn OFF fan */
          AMT49406_SetSpeed(0);
          AMT49406_SetBrake(1);
          Delay_Ms(200);
          AMT49406_SetBrake(0);

          current_level = 0;
          state = STATE_OFF;
          off_adc_timer_ms = 0;
          if (!Battery_IsCharging()) {
            ws2812_clear();
            ws2812_update();
            prev_charging = 0;
          }
          continue;
        }
        AMT49406_SetSpeed(SPEED_THROTTLE_TABLE[current_level]);
        speed_feedback_timer_ms = SPEED_FEEDBACK_DELAY_MS;
      }
      /* Long Press (1.5s): Turn off immediately */
      else if (btn_ev == BUTTON_EVENT_LONG_PRESS) {
        /* Press and hold for 1.5s -> Turn OFF fan */
        AMT49406_SetSpeed(0);
        AMT49406_SetBrake(1);
        Delay_Ms(200);
        AMT49406_SetBrake(0);

        current_level = 0;
        state = STATE_OFF;
        off_adc_timer_ms = 0;
        if (!Battery_IsCharging()) {
          ws2812_clear();
          ws2812_update();
          prev_charging = 0;
        }
        continue;
      }

      /* Poll ADC every 500ms while running */
      running_adc_timer_ms += 20;
      if (running_adc_timer_ms >= 500) {
        running_adc_timer_ms = 0;
        Battery_Update(current_level);
      }

      /* Check critical battery cutoff (< 3.05V) */
      if (Battery_IsCutoff()) {
        AMT49406_SetSpeed(0);
        AMT49406_SetBrake(1);
        for (uint8_t i = 0; i < 3; i++) {
          ws2812_set_all(COLOR_RED);
          ws2812_update();
          Delay_Ms(250);
          ws2812_clear();
          ws2812_update();
          Delay_Ms(250);
        }
        AMT49406_SetBrake(0);
        current_level = 0;
        state = STATE_OFF;
        off_adc_timer_ms = 0;
        if (!Battery_IsCharging()) {
          ws2812_clear();
          ws2812_update();
          prev_charging = 0;
        }
        continue;
      }

      /* LED Display Logic while running:
       * 1. If speed level just changed: Display speed feedback (1-4 Cyan, 5-8
       * Purple, 9-10 Lime) for 1.5s
       * 2. After 1.5s timeout:
       *    - If charging: Indicate charge status (0.25 Hz breathing)
       *    - If not charging: Display normal battery bars (Red, Orange, Lime,
       * Green) */
      if (speed_feedback_timer_ms > 0) {
        speed_feedback_timer_ms = (speed_feedback_timer_ms >= 20)
                                      ? (speed_feedback_timer_ms - 20)
                                      : 0;
        ws2812_show_speed_level(current_level);
      } else {
        if (Battery_IsCharging()) {
          charging_phase_ms = (charging_phase_ms + 20) %
                              4000; /* 0.25 Hz breathing (4000ms period) */
          ws2812_show_charging(Battery_GetBars(), charging_phase_ms,
                               Battery_IsFullCharge());
        } else {
          blink_counter = (blink_counter + 1) % 25;
          ws2812_show_battery_bars(Battery_GetBars(), Battery_IsLow(),
                                   (blink_counter < 12));
        }
      }

      Delay_Ms(20);
    }
  }
}

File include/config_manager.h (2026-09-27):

#ifndef __CONFIG_MANAGER_H
#define __CONFIG_MANAGER_H

#include <ch32v00X.h>
#include <stdint.h>

#ifdef __cplusplus
extern "C" {
#endif

/* ============================================================
 * Configuration Profile Selector
 * Choose which dumped profile to compile into firmware:
 *   Set AMT49406_CONFIG_SELECT to:
 *     0 -> amt49406_config0.json (Rated Speed = 314, Current = 628, 12V)
 *     1 -> amt49406_config1.json (Rated Speed = 400, Current = 800, 12V)
 * ============================================================ */
#ifndef AMT49406_CONFIG_SELECT
#define AMT49406_CONFIG_SELECT   1   /* 0: Config0, 1: Config1 */
#endif

typedef enum {
    CONFIG_STATUS_MATCH = 0,     /* EEPROM matches active configuration values */
    CONFIG_STATUS_MISMATCH,      /* EEPROM does not match, needs programming */
    CONFIG_STATUS_ERROR          /* I2C or hardware communication fault */
} config_status_t;

typedef struct {
    uint8_t  addr;
    uint16_t value;
} eeprom_entry_t;

#define GOLDEN_CONFIG_COUNT  13

/* ============================================================
 * Profile 0 (amt49406_config0.json)
 * Motor: 12.0V, 7 PP, Rated Speed 314, Current 628, Observer P50 I30
 * ============================================================ */
#define CFG0_PROFILE_NAME       "Config 0 (Rated Speed 314, 12V)"
#define CFG0_REG_8              16698   /* Rated Speed raw = 314, open loop */
#define CFG0_REG_9              29040   /* Motor Resistance = 113, accel */
#define CFG0_REG_10             25204   /* Rated Current = 628, spd mode */
#define CFG0_REG_11             54400   /* Startup mode = 1, power ctrl */
#define CFG0_REG_12             1842    /* Observer P = 50 */
#define CFG0_REG_13             30      /* Observer I = 30 */
#define CFG0_REG_15             2432    /* Deadtime = 9 (400ns) */
#define CFG0_REG_16             10860   /* OCP = 4 */
#define CFG0_REG_17             640     /* I2C_SPD_MODE = 1 (bit 9) */
#define CFG0_REG_18             2816    /* IPD current threshold */
#define CFG0_REG_20             11836   /* Rated Voltage = 12.0V, Rsense = 12.4mOhm */
#define CFG0_REG_21             32800   /* Standby mode = 1 */
#define CFG0_REG_22             33374   /* Brake mode = 1, Ratio = 30 */

/* ============================================================
 * Profile 1 (amt49406_config1.json)
 * Motor: 12.0V, 7 PP, Rated Speed 400, Current 1000, Observer P50 I30
 * ============================================================ */
#define CFG1_PROFILE_NAME       "Config 1 (Rated Speed 400, 12V)"
#define CFG1_REG_8              16784   /* Rated Speed raw = 400, open loop */
#define CFG1_REG_9              29040   /* Motor Resistance = 113, accel */
#define CFG1_REG_10             25376   /* Rated Current raw = 800 (~2174 mA), spd mode */
#define CFG1_REG_11             54400   /* Startup mode = 1, power ctrl */
#define CFG1_REG_12             1842    /* Observer P = 50 */
#define CFG1_REG_13             30      /* Observer I = 30 */
#define CFG1_REG_15             2432    /* Deadtime = 9 (400ns) */
#define CFG1_REG_16             10860   /* OCP = 4 */
#define CFG1_REG_17             512     /* I2C_SPD_MODE = 1 (bit 9), demand 0 */
#define CFG1_REG_18             2816    /* IPD current threshold */
#define CFG1_REG_20             11836   /* Rated Voltage = 12.0V, Rsense = 12.4mOhm */
#define CFG1_REG_21             32800   /* Standby mode = 1 */
#define CFG1_REG_22             33374   /* Brake mode = 1, Ratio = 30 */

/* Active profile data references */
extern const eeprom_entry_t ACTIVE_EEPROM_CONFIG[GOLDEN_CONFIG_COUNT];
extern const char* const ACTIVE_CONFIG_NAME;

/* Verification and Flashing API */
config_status_t Config_VerifyEEPROM(void);
config_status_t Config_FlashEEPROM(void);

#ifdef __cplusplus
}
#endif

#endif /* __CONFIG_MANAGER_H */

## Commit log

2026-09-27 feat: initialize M2 Plus firmware project with core hardware drivers, battery management, and GUI configuration tools
2026-09-29 added firmware simulator and fixed wled control
    [battery.c, battery.h, button.c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]
2026-09-29 docs: add M2 Plus hardware documentation, schematics, and PCB assets
2026-09-29 added cad files for enclosure & edited readme
    [3D_breakout_2026-09-29.step, bottom_shell.stl, button.stl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]

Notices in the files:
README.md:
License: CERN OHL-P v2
